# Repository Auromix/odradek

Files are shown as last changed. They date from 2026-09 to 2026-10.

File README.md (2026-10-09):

# Odradek

Current base candidate: [B06-COMPACT-07-DFM](engineering/base_b06/README.md), retaining the approved one-piece nose, wings and neck. Its build no longer requires arm assets; a separate metal test fixture and 21-test plan cover independent base qualification. [Shared base authority](docs/engineering/base-authority.md) applies to all arm-body work in Auromix/odradek; B04/B05 are historical references. Physical production qualification remains blocked.

**A 7-DOF desktop arm with a detachable four-petal luminous gripper, expressing attention through orientation, opening, and light.**

[中文说明](README.zh-CN.md) · [Design brief](docs/design-brief.md) · [Comparison](docs/concept-comparison.md) · [Nickname candidates](docs/nickname-candidates.md) · [Roadmap](docs/roadmap.md)

**Selected appearance directions:** the [dedicated selected-design folder](docs/concepts/selected/README.md) contains only the four-petal open silhouette and option B shield-shaped base. Other proposals and comparisons remain in the [research artwork directory](docs/concepts/README.md). Selection is not a manufacturing release.

**Current base work:** refine the single B06 source and integrate the arm against it. The approximately 239×224×71 mm exterior has five printed parts and underside fixings. The hidden clamp/inward box shelf have original CAD; IO and PWM lamp boards have native manufacturing exports. Prototype cables, actual connector release, fit and load qualification remain unfinished; this is not a complete base manufacturing release.

**2026-09-28 checkpoint:** preserve the current research and drafts without adding complexity. The preferred head uses positive single-input synchronization and permits one opposed petal pair to carry the grasp. Passive differential studies remain comparisons. [Saved scope and draft status](docs/engineering/checkpoint-2026-09-28.md).

Odradek is an independent Auromix robotics project sharing design material for noncommercial research and hobby use inspired by the articulated scanner in *Death Stranding*. The intended application is practical manipulation from a fixed desktop base. Mechanical design, appearance, and behavior develop together.

**Stage: engineering research; the head drive is being redesigned for a confirmed ≤1-second empty closed–open–closed cycle.** Gripping is the primary function and the illuminated petal face is the contact face. The user has confirmed a 2 kg net object plus head mass, approximately 700 mm reach, EtherCAT, GMSL/GMSL2 cameras, internal cabling and external computing. P16 actuators cannot meet the new cycle; their CAD and electrical branch remain historical references. The existing 7+4 assembly does not demonstrate the new speed requirement. See [current requirements](docs/engineering/fast-grasp-requirements01.md). No manufacturing release or tested 2 kg prototype exists.

## R5: single-drive head and separate arm body

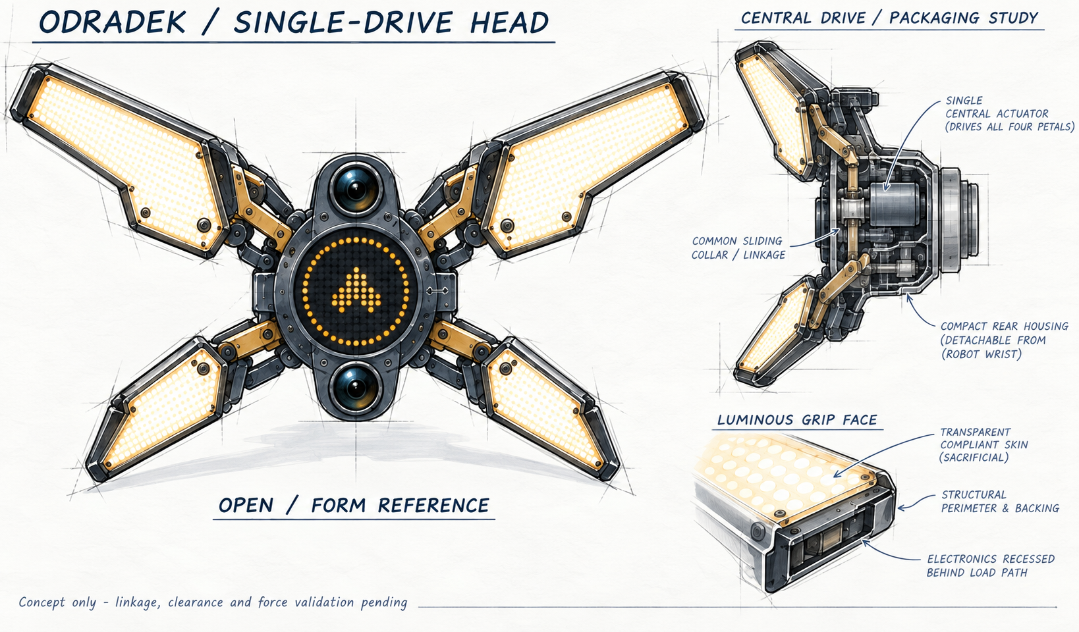
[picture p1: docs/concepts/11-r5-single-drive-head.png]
Single central drive and four shaped luminous petals


One concealed central actuator drives four coupled petals; their luminous faces also grip. The seven-axis body is developed separately with slender proportions and a detachable tool flange. [See both concept sheets and the current design brief](docs/r5-modular-design.md). Generated illustrations guide appearance; linkage, clearance and load capacity require engineering validation.

The latest engineering includes [revised layered petal STEP and drawings](docs/engineering/r5-petal-form02.md), a [fold-then-radial path and passive differential study](docs/engineering/r5-stage01.md), a [detachable eRob wrist adapter](docs/engineering/r5-wrist-erob01.md), and a [separate arm mass/reach study](docs/engineering/r5-body01.md). Everyday boxes, bottles and cans of approximately **50–120 mm gripping width** are the first target. Bare-petal geometry now has a continuous separation bound, but the physical mechanism, final closed posture and complete grasp range remain unqualified. The earlier [single-slider Blender rig](docs/engineering/r5-linkage-blender01.md) remains a separate comparison. See the [current baseline](docs/engineering/current-baseline.md) for evidence and remaining work.

The [native radial-candidate Blender model and guide](docs/engineering/r5-stage-blender01.md) contain 28 actual petal CAD meshes, including contact poses for an Ø80 mm cylinder and a 50×120 mm rectangular box. One mean input and three passive review offsets express the differential constraint; the physical transmission, central module and time simulation are not included.

## Engineering package

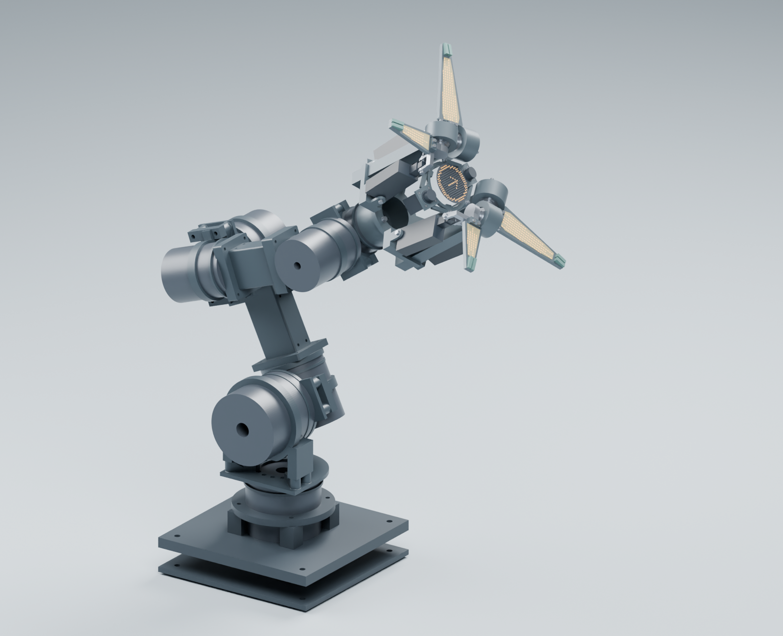
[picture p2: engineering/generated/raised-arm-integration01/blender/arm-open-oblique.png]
Existing structural review assembly — historical P16 head


This model combines 24 original link parts, a shoulder raised by 35 mm, the corrected base and the 697-object HEAD-INTEGRATED03 snapshot. Joint housings in Blender remain catalog envelopes; arm fasteners, harnesses and exterior guards are not fully integrated. The central pixel display is a separate visual preview. [The raised candidate](docs/engineering/raised-arm-integration01.md) passes the stated actual-BREP checks for ten poses, including the historical shoulder-collision pose. These discrete checks do not qualify trajectories or payload. [Current baseline and hardware choices](docs/engineering/current-baseline.md) separate the conditional eight-node P16 branch from earlier alternatives.

| Package | Evidence and scope |
|---|---|
| [Engineering index](docs/engineering/README.md) | Requirements, assumptions, source records, and release checklist |
| [R4 layout and grasp](docs/engineering/r4-layout-and-grasp.md) | Same-parameter geometry, closure proof, conditional contact calculations, and optical sightlines |
| [Existing native Blender / historical P16 head](engineering/generated/raised-arm-integration01/blender/odradek-integrated-7-plus-4.blend) / [model guide](docs/engineering/raised-arm-integration01.md) | 736 product meshes, 11 controls, persistent actuator linkage drivers; geometric review only |
| [Integrated head STEP and evidence](docs/engineering/head-integrated03-study.md) / [coupled dynamics](docs/engineering/articulated-dynamics-review.md) | Actual candidate solids, frozen board placement and explicit mass/inertia assumptions |
| [Historical layout](docs/engineering/r4-layout-and-grasp.md) / [subassembly scenes](docs/engineering/subassembly-blender-review.md) | Earlier design stages retained for traceability |
| [A3 review drawings](engineering/generated/layout/ODR-R4-assembly-review.pdf) | Axes, dimensions, and orthographic mesh views |
| [Manual finger fixture](engineering/generated/finger-fixture/README.md) / [joint interface coupons](docs/engineering/interface-coupon-guide.md) | Unpowered printable geometry checks with dimensions |
| [Hardware BOM](docs/engineering/hardware/bom.csv) / [optical bench](docs/engineering/hardware/optical-bench-build.md) | Sourced component candidates and a concrete dual-fisheye bench chain |
| [Reproduce the calculations and CAD](engineering/README.md) | Dependencies, generation order, units, and limitations |

The old [finite-pad contact counterexample](docs/engineering/finite-pad-contact-study.md) remains documented. HEAD-INTEGRATED03 now combines the revised CONTACT-02 pads and retention, narrowed CARRIER02 roots, lamp cavities, board placement and EXT24. Its 17 scoped continuous checks pass nominal geometry conditions; dynamic harnesses, tolerances, deformation and grasp testing remain unresolved. Conditional force calculations are not a measured payload rating.

## Historical R3: silhouette, closure and contact

The larger upper / smaller lower, left-right mirrored open silhouette is selected. The upper fisheye tilts upward and the lower downward; the amount remains open pending near-grasp visibility checks.

The study identifies three issues: unequal rigid lengths do not fold into one short common-depth pod, wide plates can collide before their tips reach the center, and forward curling turns the original luminous face toward the object. The leading candidate keeps each plate intact, uses different limits and real depth offsets, and places proud contact pads / structural borders on the light-facing side with recessed windows.

The [geometry study](docs/r3-closure-study.md) includes counterexamples and a continuous-domain separation result for an illustrative four-box model. This does not validate the full head or a stable grasp. The artwork's stow panel is an envelope study, not a final closed pose.

## Current direction: a detachable four-petal head

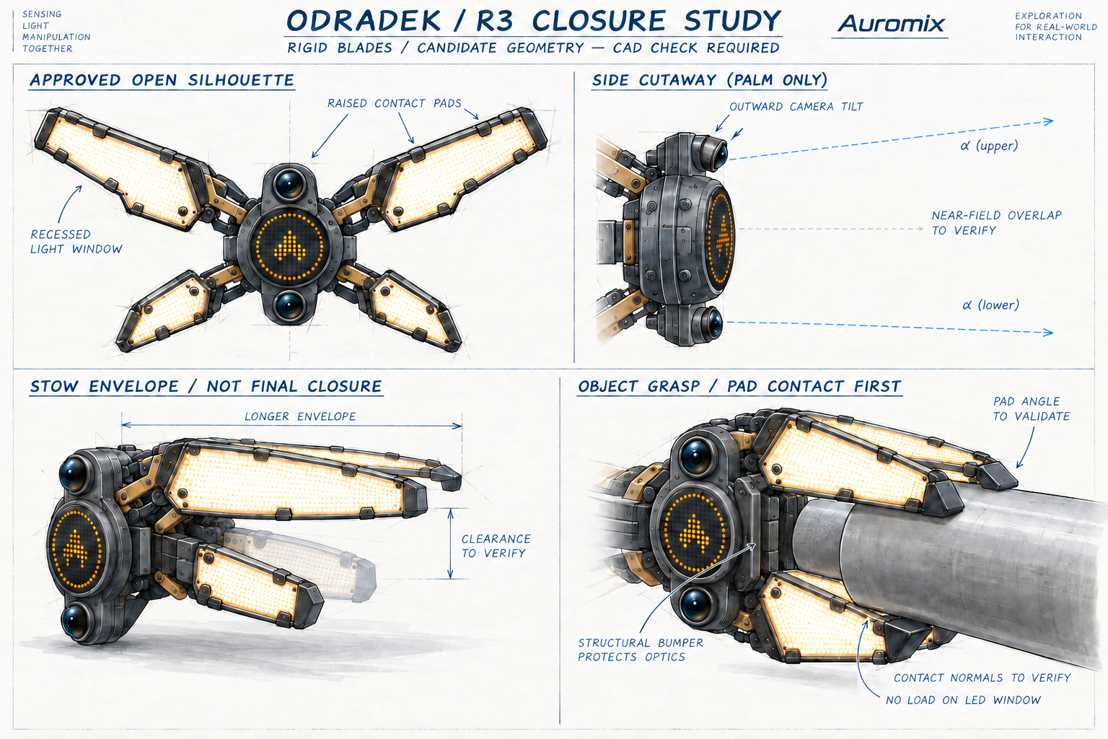
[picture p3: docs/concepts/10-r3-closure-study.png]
R3 silhouette, camera, and contact study


- **Seven arm DOFs; a single-drive four-petal head is now the preferred route.** J7 rolls the head about its front normal. One motor with three mechanically coupled followers is permitted; linkage mapping and passive compliance remain to be designed.
- **Two close petals on each side, with left/right mirror symmetry and different upper/lower proportions.** Longer upper and shorter lower petals avoid 180-degree rotational symmetry. The grouping is inspired by the XPENG logo composition; it does not require mechanically coupled pairs.
- **The light petals are the fingers.** Forward curling turns the light face inward. The latest requirement makes the illuminated face itself the gripping face; the contact skin and load-bearing support are being redesigned. Earlier proud tip pads are a historical contact study. Empty full closure must reach a mechanical limit with real clearances; it does not imply a sealed pod or four tips meeting at one point.
- **One circular LED display in the center.** Ring graphics use pixels at its perimeter. The four fingers provide lighting. Two fisheye cameras sit above and below the screen, tilt upward/downward respectively, and rotate with the head.
- **The detachable boundary is after the J7 output flange.** One concealed central actuator and local execution interfaces are proposed within the head; connection specifications remain open.

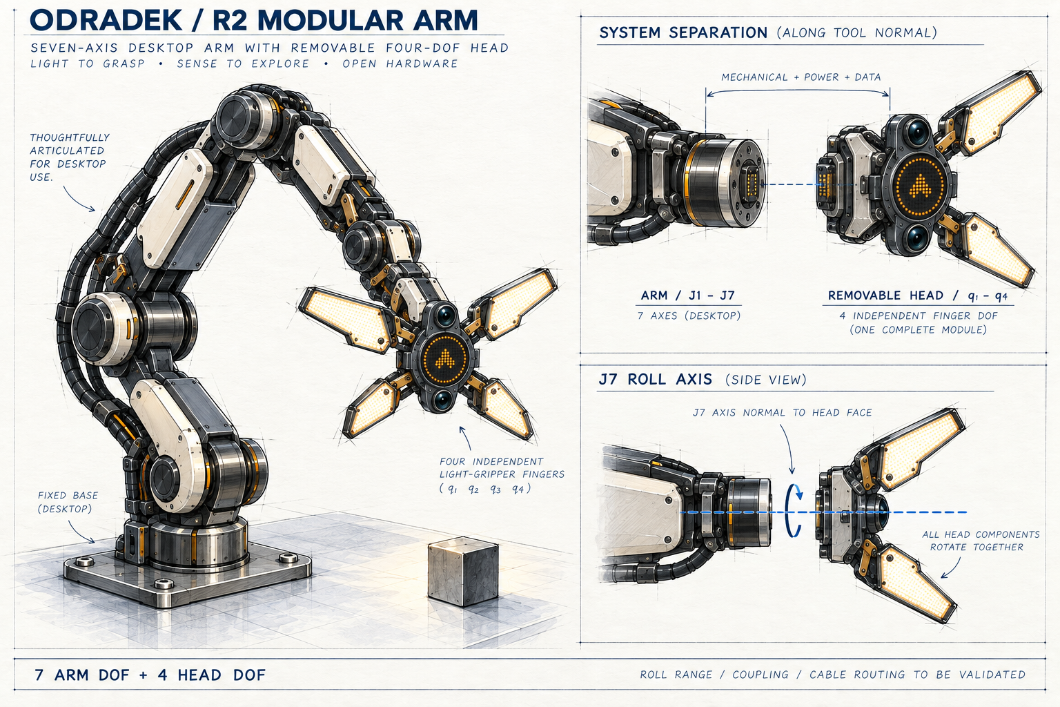
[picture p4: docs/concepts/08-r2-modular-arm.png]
Arm integration, detachable interface, and J7 axis


The roll sketches show finite-angle pose intent without defining travel. Open, grasping, and fully closed geometry must be reconciled in one CAD model; the R2 compact protective pod is now a historical assumption. Mechanical breathing is limited to empty, task-permitted operation; expression must not change an active grasp.

## Three, four, or five petals

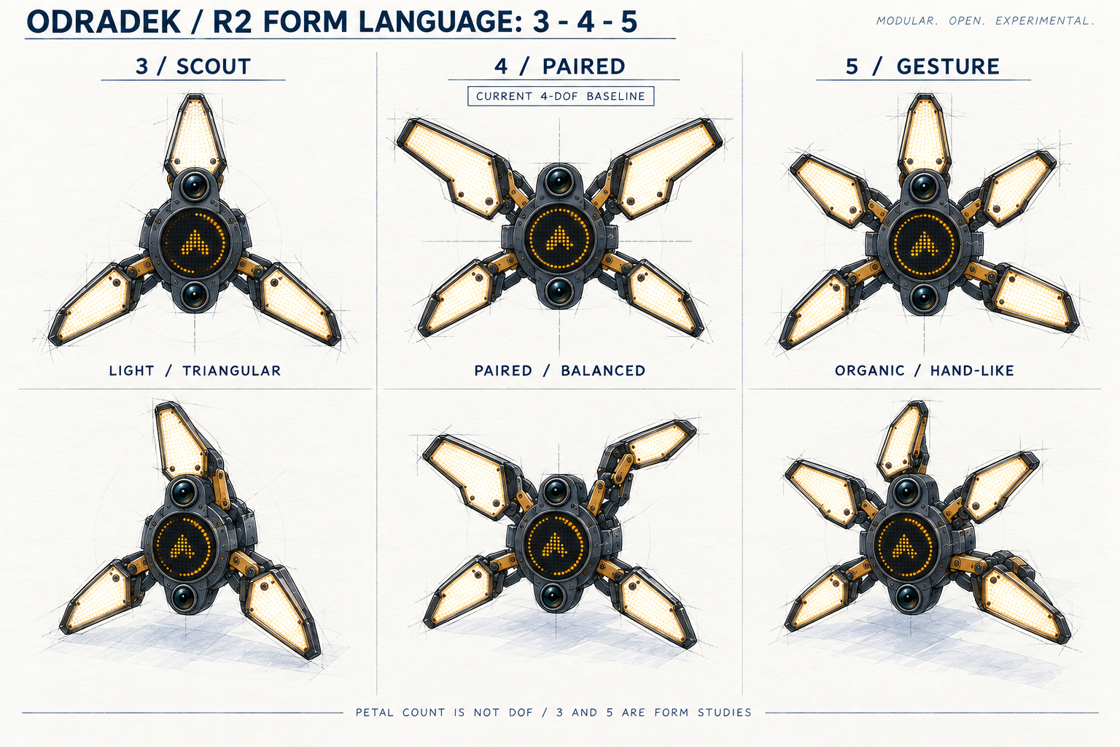
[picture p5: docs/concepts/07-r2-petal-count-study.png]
Same-scale petal-count study


| Count | Visual character | Role |
| --- | --- | --- |
| 3 | Light triangular silhouette; instrument or alien-tool associations | Aesthetic comparison |
| **4** | Two visually grouped pairs; balance between tool and creature | **Four shaped petals, single-drive coupling permitted** |
| 5 | Denser flower or biological silhouette; a hand-like reading needs an offset petal | Aesthetic comparison |

Petal count is not a DOF count. Three- and five-petal variants would require their own motion allocation; the latest direction permits a single actuator with coupled motion.

## Nickname candidates

**Odi** is the leading suggestion for continuity with Odradek; **Lumo** emphasizes light and breathing. Noto, Piko, Tavi, and Filo are additional options. See the [shortlist](docs/nickname-candidates.md). No nickname has been selected; the project and repository remain Odradek.

## Process and next steps

Research → R0 form exploration → R1 luminous fingers → R2 7+4 DOF and modular head → R3 silhouette and closure → **R4 sourced components, mathematics, CAD, and geometry fixtures** → complete load paths and harness routes → physical task and manufacturing validation.

The [gallery](docs/gallery.html) retains original R0/R1 artwork and exact prompts for traceability. R1's separate physical light annulus and finger-count candidates are superseded by R2.

| Document | Contents |
| --- | --- |
| [Design brief](docs/design-brief.md) | Confirmed requirements, concept assumptions, and open inputs |
| [Comparison](docs/concept-comparison.md) and [behavior](docs/behavior-spec.md) | Form, grasp, light, and attention studies |
| [Decisions](docs/decisions.md) and [roadmap](docs/roadmap.md) | Evolution and route to reproducible hardware |
| [Sources](docs/sources.md) | Research and reference roles |
| [Generation](docs/generation.md) and [review notes](docs/review-notes.md) | Prompts, AI assistance, and specific visual limitations |

Current open items include the shoulder's usable motion range, installed holding/thermal performance, complete controller and harness design, contact/fastener qualification and manufacturing tolerances. See the [release checklist](docs/engineering/release-checklist.md).

## License and commercial permissions

New original artwork, documentation, research scripts, parameters, and models are offered under **[CC BY-NC 4.0](LICENSE)**. Noncommercial research, study, hobby use, adaptation, and sharing are permitted under its terms. Sharing requires attribution, license information, and indication of changes. Commercial use requiring authorization needs a [separate written license from the authors](https://github.com/Auromix/odradek/issues/new?template=commercial-license.yml).

**Prior Apache-2.0 grants through `2d7d00f` and marked-script PolyForm grants in `698736a` through `c4f1fde` remain valid.** See [licensing scope and history](LICENSING.md), including the explicit limitations of applying CC to engineering research software. Future production control firmware needs a suitable separate license decision. Copyright notices do not themselves control all functional hardware manufacture.

The noncommercial restriction means this is not open source under the OSI definition. Contributions in English or Chinese are welcome; see [CONTRIBUTING](CONTRIBUTING.md). Third-party reference images are not included or relicensed. This project has no official affiliation with *Death Stranding*, KOJIMA PRODUCTIONS, or XPENG.

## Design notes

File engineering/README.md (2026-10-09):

# 可复现计算与建模

## 当前底座唯一入口

[B06-COMPACT-05-LIGHT](base_b06/README.md)是当前底座候选；沿用已确认的主罩外观；前鼻、双翼和颈台一体，五件打印结构，增加独立PWM灯板与隐藏M2固定，实际切片检查完成。所有本体模块遵循[底座同源规则](../docs/engineering/base-authority.md)，读取同一模型，不在本体目录维护可编辑的替代底座。B04/B05与下文R4底座只作历史研究。

新增原创工程研究源稿、参数及模型按 CC BY-NC 4.0 共享。历史 Apache / PolyForm 授权继续有效；CC 缺少软件专用条款的限制见 [LICENSING.md](../LICENSING.md)。依赖库保留各自许可，不打包重新许可。

`kinematics.py` 使用空间轴乘积形式计算位姿、Jacobian、重力、质量矩阵及数值 Christoffel 项；`gripper.py` 定义四片各自的径向转动与接触力映射。所有计算使用米、千克、秒和弧度；外部配置中的角度字段名称明确带 `_deg`。

代码不连接硬件、不发送运动指令。数值 IK 不包含碰撞或线束约束，质量和惯量假设必须在使用结果前核对。摩擦抓持下界不能作为力闭合证明。

## R5当前模块入口

[FORM02真实灯片](../docs/engineering/r5-petal-form02.md) → [STAGE01折叠/径向数学](../docs/engineering/r5-stage01.md) → [STAGE-BLENDER01原生模型](../docs/engineering/r5-stage-blender01.md)构成当前裸片研究链。Blender生成器为 `r5_stage_blender01.py`，先由CadQuery准备网格，再由Blender生成并以禁用自动脚本的进程重开核对。具体命令、输入及检查边界见模型说明。新的[eRob腕部接口](../docs/engineering/r5-wrist-erob01.md)单独保存，不与旧RH/P16整臂混成制造总装。

## 环境与单位

本版实际使用 Python 3.12.14、CadQuery 2.8.0 / OCP 7.9.3.1.1、Blender 4.5.14 LTS；其余 Python 版本见 [requirements-lock.txt](requirements-lock.txt)。记录的是本次环境快照，不保证所有平台均有对应二进制包。

```sh
python3.12 -m venv .venv
.venv/bin/python -m pip install -r engineering/requirements-lock.txt
```

以下命令从仓库根目录运行，`python` 应指向上述环境。Blender 使用自身 Python，不要往其中安装 CadQuery。需要中文图纸的命令通过 `--font` 传入可用的中文 TrueType 字体；字体不随项目分发。

参数源为 [r4-layout.json](parameters/r4-layout.json)。CAD 输入输出为 mm；数学核心为 m / kg / s / rad；Blender 网格转换为 m 后以 mm 显示。修改几何参数后必须按依赖重生成，不能只改渲染图。

## 数学与静力

```sh
python engineering/verify_math.py
python engineering/arm_screening.py
python engineering/head_mass_sensitivity.py
python engineering/review_arm_screening.py > docs/engineering/analysis/arm-static-independent-review.json
python engineering/grasp_screening.py
python engineering/finite_pad_contacts.py
python engineering/structure_screening.py
python engineering/structure_screening.py --check
```

数学回归覆盖解析单摆、耦合 2R、外力矩、Jacobian、势能梯度、动力学能量恒等式、可达/不可达 IK 和接触虚功。机械臂静力复核使用独立旋转递推与重量叉乘；梁模型有 60 项公式/数值检查。它们均不代表硬件验证。当前实机惯量、摩擦、转子耦合和热条件未知，不从这些检查推导额定速度或精度。

有限双垫研究读取已有主 CAD，计算物体先接触的实体、八点共享四轴力矩以及 BREP 反例。当前 Ø80 圆柱先碰骨架/灯窗，不能由旧单点例题推出可抓取；完整结果见[接触研究](../docs/engineering/finite-pad-contact-study.md)。

## 几何、图纸与 Blender

```sh
python engineering/build_layout.py
python engineering/certify_petal_separation.py
python engineering/check_layout.py
python engineering/check_optical_sightlines.py
python engineering/draw_layout.py --font /path/to/Chinese-font.ttf
blender --background --factory-startup --python engineering/build_blender.py
```

`build_layout.py` 读取当前参数、接口提取记录及已保存的指驱动布置输入；输出解析 STEP、单件 STEP/STL 和 manifest。STEP 可能包含导出时间戳，重新生成后的文件哈希不必字节一致；须重新生成引用这些文件哈希的证书并审阅几何变化。更换传动、支承或结构不能只复制旧分析结论。

分离证明只覆盖四片结构、灯窗和八垫的名义平面实体；采样碰撞另列对象和范围。碰撞布尔必须遍历每个 solid；直接对厂商 compound 求交会漏报，详见[安装接口研究](../docs/engineering/mount-interface-study.md)。

Blender 保存 7＋4 层级和 360 帧几何演示，另输出三视角渲染。原生层级 TCP 与独立矩阵计算在三姿态下检查到小于 0.001 mm。动画不含真实速度、加速度、控制或抓取轨迹资格验证。

新增 LINK56、固定底座及 CONTACT-02 的[原生分组件检查包](../docs/engineering/subassembly-blender-review.md)独立保存为 `generated/component-reviews/odradek-r4-subassemblies.blend`，含三个场景和五张渲染。使用 `export_component_reviews.py --output /tmp/odradek-component-meshes.json` 从已有 STEP 导出，然后由 Blender 执行 `blender_component_reviews.py -- --mesh-json /tmp/odradek-component-meshes.json`。它没有将三个研究机械集成为新整臂。

更新的[整体结构检查包](../docs/engineering/integrated-blender-review.md)保存为 `generated/integrated-arm-preview/odradek-integrated-7-plus-4.blend`，已合并六段24原创连接件、底座和HEAD03，736产品网格、11控制量。复现用 `export_integrated_arm_preview.py` → `blender_integrated_arm.py` → `review_integrated_blend.py`；具体命令与27条持久驱动、697件独立闭合CAD对照见说明。历史reach已查到肩部真实碰撞，不是可执行姿态；外壳、线束和完整臂侧紧固件尚未建成。

独立 [P16-PACK-01](../docs/engineering/gripper-linear-packaging-study.md) 把真实线性执行器接口、双剪销叉和近根支承接到 CONTACT02，尚缺整头载体。执行 `python engineering/p16_packaging_study.py --vendor-dir /path/to/vendor-reference` 后，再运行 `python engineering/p16_pin_stack_drawing.py` 和 `python engineering/p16_packaging_verify.py --vendor-dir /path/to/vendor-reference`。原厂CAD仅作为本地核对输入，公开包只包含原创保守包络；使用跳过检查的调试选项不能复用完整验证结论。

## 无动力打印件与接口研究

独立上灯片 [ULP-02原生KiCad](electronics/upper-petal-prototype/ulp02/kicad/README.md)含真实四层PCB、原理图、重放布线、逐针核对和C99例程。执行其 `rebuild.py --kicad-cli /path/to/kicad-cli --kicad-python /path/to/kicad-python` 可从源完整重建并实际运行ERC/DRC、317针网表和113灯点校验，再导出Gerber/钻孔审查文件。已在KiCad10.0.6独立重跑成功；这是电测样片，不是已经适配CONTACT02的正式灯板。

```sh
python engineering/build_interface_coupons.py --font /path/to/Chinese-font.ttf
python engineering/build_finger_fixture.py --font /path/to/Chinese-font.ttf
```

接口片使用已提取的真实孔坐标；单指台架包含打印方向、孔坐标、STEP/STL、五页尺寸图及几何限位检查。只能用于无动力形态/装配；与金属生产设计不同。厂商 STEP 不重新分发，需要重新提取或运行安装研究时，按对应[接口研究说明](../docs/engineering/mount-interface-study.md)传入自行取得的原厂文件。

## 文件成熟度

`generated/layout` 是 74 组几何布局，含明显占位及已记录的待修正问题；`generated/interface-coupons` 和 `generated/finger-fixture` 是无载打印检查件；`generated/mount-study` 是安装接口候选。**均不是完整制造发布包。** 参见[发布清单](../docs/engineering/release-checklist.md)，不要把能打开 STEP、网格水密或有限采样不碰撞等同于可承受 2 kg。

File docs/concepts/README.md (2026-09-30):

<!-- SPDX-License-Identifier: CC-BY-NC-4.0 -->
# 图稿目录

## 已选方向

[selected/](selected/README.md) 单独收录用户已选的四瓣末端展开外形与 B 收腰盾形底座。后续查看收敛图从这里进入。

## 研究与历史比较

[proposals/](proposals/README.md) 存放沿已选方向继续深化、待确认的新图，当前为 B03 内收盒架与靠墙布置；B02 外挂竖盒保留作历史。

本级带编号的图稿保留研究过程，不视为最终选项。R5 最新生成图也不自动表示用户已确认。

| 图稿 | 定位 |
|---|---|
| [11-r5-single-drive-head.png](11-r5-single-drive-head.png) | 当前末端深化提案，含未定传动布置 |
| [12-r5-arm-body.png](12-r5-arm-body.png) | 当前本体外观提案，未获整张图确认 |
| [13-base-study01.png](13-base-study01.png) | 历史 A/B/C 比较板；仅 B 外形被选定 |
| 00–10 各轮概念图、11-r3-geometry-check.png | 形态发散、历史状态或几何研究 |

[历史综合图集](../gallery.html) 保留完整过程；[决策记录](../decisions.md)说明每次选择的范围。工程输出继续放在原 engineering 目录，不因归档成为制造定稿。

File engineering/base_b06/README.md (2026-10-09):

<!-- SPDX-License-Identifier: CC-BY-NC-4.0 -->
# B06 当前底座：COMPACT-07-DFM 独立验证候选

开始打样前阅读 [首件打印与PCB准备](first-sample.md)，按当前五件STL和CONTROL01文件操作。

2026-10-09 CONTROL-01 增量：就地5V及STM32前灯控制候选已集成同一原生IO板和Blender模型，固件/主机协议数字测试通过。新增元件体与插合预算、既有五件打印切片进行同版复核。**当前IO PCB重建铺铜、保存复开后DRC为0**；本版26元件制造文件位于 `b06-io-control01`，历史13元件导出不可混用。详见[灯控候选与修复步骤](../electronics/base-io-b05/controller/README.md)。物理测试仍为0/21，未生产放行。

这是 Auromix/odradek 唯一当前底座源。外观、装配与接口板继续在同一仓库收敛，B04/B05保留为历史。**当前尚不是完整底座的制造放行包**；缺口见下方，不用几何检查替代载荷、真实插头或电气测试。

默认建模与验证不读取机械臂文件，机械臂仅为可选集成参考。[接口定义](interface-contract.json)固定法兰/供电/通讯边界；[独立验证方案](standalone-validation.md)、[21项验证计划](validation-plan.json)和[生产资格状态](build/qualification/qualification-status.json)覆盖不装臂时的完整底座检查。当前实物记录全部未测，生产状态BLOCKED。

2026-10-10 [底座—臂同源交接](arm-handoff.md)：底座优先，臂侧先适配；当前模型以 B06 文件指纹为准，过时上下文检查失败。该检查不代替实际拼接或载荷验收。

主罩维持约239×224×71 mm，前鼻、双翼与颈台一体；五件打印件适配256×256×256 mm打印空间，床边检查余量每侧5 mm。颈口Ø136，轴心XY(0,75)，Z0桌面，+Y朝桌内。主视觉面不新增固定孔。为承力底板增加后部下沿退出口，后盖保留四个独立接口窗。

## 当前文件

- [制造定义](manufacturing.md)、[分层制造BOM](build/B06-manufacturing-bom.csv)、[19步首件流转表](build/B06-first-article-traveler.csv)：纳入焊接、PCBA混合装配、端子叠层与未关闭线束，状态与实际证据分开记录。

- [Blender 总装](build/exterior/ODR-BASE-B06-COMPACT.blend)、[离线3D查看器](build/exterior/index.html)。本地预览通过HTTP打开。
- [独立试验工装3D](build/standalone-test/index.html)、[工装STEP总装](build/standalone-test/B06-standalone-fixture.step)、[工装加工评审图](build/standalone-test/drawings/B06-standalone-fixture-review.pdf)。这套工装不属于产品五件打印件，装置本身仍须校验后才能加载。
- [五件打印STL包](build/exterior/B06-print-fit.zip)、[打印件目录](build/exterior/print-parts/)。这个ZIP只包含打印件及当前几何报告，不含完整制造BOM。
- [机械BOM](build/B06-mechanical-bom.csv)与[装配顺序](assembly.md)：37行备料规划，含灯板及其隐藏紧固件，尚缺最终线束、光学垫片与外置盒电气项。
- [原生PWM灯板](../electronics/base-light-b06/README.md)、[灯板制造审计](../electronics/base-light-b06/reports/manufacturing-audit.json)、[灯板安装检查](build/exterior/light-fit-checks.json)。
- [实际切片评审](build/exterior/slice-review-checks.json)、[五件参考3MF](build/exterior/slice-review/)；参考P1S配置，实际打印机必须重新切片。
- [精确结构STEP总装](build/load-frame/B06-load-frame.step)、[分件STEP](build/load-frame/step/)、[结构清单](build/load-frame/manifest.json)。62个有效单实体（新增四条名义焊缝），包含环境和采购件包络；机械臂安装螺钉不再计入底座本体。螺纹用底孔加明确加工注释表示。
- [加工评审图PDF](build/load-frame/drawings/B06-load-frame-review.pdf)：从实际BREP生成的投影、包络、孔位表及加工注释，尚未作为全套制造图放行。
- [原生嘉立创接口板](../electronics/base-io-b05/README.md)：CONTROL-01原生板DRC0、26个实际元件，当前导出经独立审计；整板功能需首件验证。原生目录沿用B05命名，不代表采用旧底座。

## 当前结构与装配坐标

`load_frame.py`建立独立承力结构：S355上承力板、后沿腹板和双M12螺杆下夹板；6061法兰、四根金属间隔柱和向桌内延伸的可拆盒架。打印外罩/底架不传递机械臂载荷或桌夹预紧力。最大盒体预算180×150×50 mm、3 kg已获用户确认；从桌内方向(+Y)抽出，前限位条可拆。桌厚预算15–60 mm，后沿允许夹体和走线所需小间隙。

螺杆从下方用AF6内六角扳手转动。采购Ganter DIN6332-M12-100-SK与DIN6311-25-S；压脚Ø25平面朝上，经70×90×8金属分压板及2 mm保护垫接触桌底。模型只表达供应商尺寸包络，球面座、卡环与真实工具操作仍需样件核对。禁止将螺杆、压脚或承力件作为塑料STL打印替代。

法兰Ø160/ID56×12、上安装面Z58、PCD120八M6由独立接口定义固定，可连接测试适配盘或机械臂模块。四柱Ø18×29，顶底M8螺钉分别16/20 mm，名义有效咬合12.5/13.5 mm、两端尖端间隔3 mm。测试适配盘OD134可从颈口上方插入，八颗M6×20配1.6厚垫圈，名义咬合10.4 mm。机械臂OD140根座的下方装入顺序另列可选集成步骤。几何配合不等于承载证明。

接口板保持116×56×1.6 mm，额外相对冻结I/O快照位移(0,-10,+4)。板底Z24；四个安装点(X±52,Y−20/24)。原生EDA屏幕局部u/v(mm)转换为全局`(X,Y,Z)=(58-u,30-v,24)`。不缩放封装、焊盘和板框。PCB固定为M3×10，上垫面Z25.6，尖端Z15.6；内藏螺母Z19.2..21.6。金属底板对应Ø3.6孔避让螺钉末端。

双同轴另用B06-309金属支架，基座顶面保持原生H5/H6安装点(X±10,Y−8)，RF后向安装面Y−16，孔心Z35；不随RJ45/电源接口整体后移而顶穿后盖。

后盖两颗背向M3×10，轴高Z32；螺母在底架内，上装前放入。RJ45检修窗X27..49/Z23..44，48V窗X−52..−25/Z23..44，双同轴中心X±10/Z35、窗Ø14.8。板与元件仍为项目尺寸抽象，不能据此宣称原厂插头锁扣、插合基准和GMSL通道已经完整合格。

底架改由精确BREP生成后导入Blender，稀疏抬高支架避开钢板和PTH引脚；保留主罩四个隐藏M3固定点与两侧扎带耳。它不是承载底板。

## 当前验证与限制

- 五件STL：闭合、法向一致、单一面连通体、无退化/重复三角面，均通过256³包络检查。未修补失败STL；源几何重建后重新独立检查。
- 347组打印件之间、打印件与结构/I/O/灯板实体及GH插合预留交集：无超过0.01 mm³的穿透；该阈值只用于数值判断，不是加工公差。
- Blender复开：不含外部链接库或未打包图片依赖；本轮沿用独立工装的12条工具路径及底座分阶段装配工具检查；历史机械臂集成射线结果不列为本轮证据。机械臂参考未参与本次检查。
- 独立工装26个有效BREP分件；与金属底座无非预期交叠，与打印/电子件17组相交候选检查通过；12条M6/M8直线工具路径通过。工装尚无实物载荷资格。
- 13个后盖退出位置采样及四个原生EDA安装坐标通过；需要先拔插头、拆后盖螺钉。不是连续扫掠或靠墙原位拆卸证明。
- 15/30/60 mm桌厚的精确结构BREP静态检查通过。M12牙的底孔/大径包络重叠明确列为有意螺纹配合，不隐去其他干涉。
- 当前结构与采购件包络计算质量约7.5 kg，含桌夹/盒架/底架和标准紧固件，不含臂身、工装和控制盒；需减重与载荷计算后再冻结。简支梁筛查只是保守假设，不是额定载荷或有限元结论。
- 当前控制器板DRC0、Gerber/钻孔/原生网络复核通过；差分线长接近不等于整个通道已证明100Ω或EtherCAT合格。

## 完整底座打样放行仍须完成

1. 已补齐承力/盒架/同轴支架紧固件、加工孔位/螺纹/沉孔注释、装配次序和直线工具检查；仍需焊接工艺与实物工具/公差复核。
2. 已建立50×14独立PWM灯板，原生制造导出及引脚网络审计通过；当前隐藏M2安装和GH插合空间进行同版装配检查。灯窗软垫、透光样件、板上48V→5V/PWM控制电路和内部短线仍需关闭；严禁直接接48V。LED板原生STEP部分有效BREP在三角化时接缝不闭合，这些子实体明确以其原生BREP包围盒作保守干涉检查，不把替代包络当作原厂精确模型。
3. 真实电源插头/RJ45锁扣/双同轴接头与线材的插合、释放、弯曲和应变释放；现有保守包络不是采购闭环。
4. 切片及小样配合公差检查、完整制造BOM、当前PDF尺寸/孔表与STEP/STL/PCB指纹一致性。
5. 完整无动力打样装配文件放行；样件回来后按独立流程做桌夹防滑/桌面压力、通电温升/保护和链路测试。制造文件放行与带载运行放行分开。

## 复现

用含CadQuery、trimesh、manifold3d、numpy、scipy、shapely、reportlab及svglib的Python运行`verify_base.py --blender /绝对路径/Blender`；添加`--render`生成评审图片。重建默认拒绝读取臂身文件并记录输入哈希。现有切片需与实际STL的顶点及三角面匹配，不匹配即停止。机械臂参考通过`blender_compact.py -- --with-arm-root --no-render`输出到单独`build/arm-integration/`；它不是第二份底座源。修改后重新生成受影响报告及指纹，实物记录版本失配后不可沿用。

CC-BY-NC-4.0；Odradek / Auromix contributors。

2026-10-09供电修订：前灯目标由底座板就地产生5V，经内部短GH线连接；原生IO板现已加入就地5V供电，当前导出在b06-io-control01；STM32 PWM与UART命令已在原生板及固件中实现，实板仍未验证。新增元件按独立底座装配包络验证，实物供电、浪涌、温升及EMI待测。

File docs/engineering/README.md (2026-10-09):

# 工程开发记录｜R4历史与R5单驱动深化

## 当前底座唯一入口

[B06-COMPACT-07-DFM](../../engineering/base_b06/README.md)为当前同源候选，保留已确认外观；[底座同源规则](base-authority.md)定义本体引用、只读快照和更新后的联检。B04/B05及下表R4固定底座属于历史，不与B06并列维护。

本轮从概念研究进入参数化工程设计。用户要求持续推进硬件选型、机械臂与夹爪数学、Blender 结构模型及制造图，并按完成部分提交。本目录将输入、计算、供应商证据、设计产物和验证记录分别维护。

先看[FAST-GRASP01最新需求](fast-grasp-requirements01.md)和[当前基线](current-baseline.md)：灯片面必须用于正常夹持，空载完整开合≤1秒。P16退出主末端路线；既有模型与电路保留为可复现研究。七轴本体、中央屏、灯板及相机继续作为新方案输入，不能把历史研究混成已满足新要求的采购配置。

[R5单驱动末端与独立本体](../r5-modular-design.md)包含最新概念图及确认输入。[SHOULDER-RAISE03](shoulder-raise03.md)已合并让位钢块与具体螺钉；[HEAD04](head-integrated04.md)和[HEAD-POWER01](hardware/head-power01.md)归档为旧P16集成证据。

R5最新工程入口：[削肩灯片FORM02与二维图](r5-petal-form02.md)、[折叠后径向夹持/差动数学](r5-stage01.md)、[eRob可拆腕接口](r5-wrist-erob01.md)、[独立本体质量/臂展](r5-body01.md)、[轻量EtherCAT关节](hardware/r5-light-joint01.md)、[透明夹持面材料与紧固件](hardware/r5-petal-hardware01.md)。盒体、瓶罐50–120mm为确认目标，现阶段没有完整抓取范围资格。较早[单滑块数学](r5-link01.md)、[一个主控的原生Blender](r5-linkage-blender01.md)和[折返带传动](hardware/r5-folded-drive01.md)保留为固定根轴比较方案，不与新径向机构混算。

## 当前可查看的工程结果

| 部分 | 入口 | 已有证据及边界 |
|---|---|---|
| 两瓣主夹持新口径 | [TWOCONTACT01](r5-twocontact01.md) | 同步四瓣先夹盒体较大尺寸；每片约49N初筛与804N根轴承反力，有限接触斑抗转仍是条件模型 |
| 当前径向候选 Blender | [STAGE-BLENDER01](r5-stage-blender01.md) | 28个真实灯片CAD网格，展示圆柱与长方盒的不同半径接触；一个主动输入加被动评审偏移，未模拟真实差动传动 |
| 径向折叠随动器与根轴承 | [CAM-HARDWARE01](hardware/r5-cam-hardware01.md) | CFS4、双607/8-2Z、真实安装栈与逐片受力；保留大悬伸、远端接触及低摩擦下的不足 |
| 径向载体与分体根轴 | [CARRIER01](r5-carrier01.md) | 40种单件、实际短轴/曲柄/轴承/导槽及2页名义尺寸图；内件C4、无硬止挡/掌体/滑轨，256.53mm外包尚未外观协同 |
| 差动钢索、滑轮与终端 | [CABLE-HARDWARE01](hardware/r5-cable-hardware01.md) | 一套升级索轮候选、名义50/100N条件筛选；全公差、端部保持力和完整索路尚未验证 |
| 七轮差动索路包装 | [ROUTE01](r5-route01.md) | 恒索长中心线、真实轮径、偏置支承载荷与独立复算；仅轮组已到根铰后239.05mm，不作为紧凑头定案 |
| 单电机被动开合动力学 | [PASSIVE01](r5-passive01.md) | 上下瓣不同步与首次止挡的独立数学核对；先碰止挡后不能继续套用绷紧钢索约束，完整周期仍未验证 |
| 实际载体质量与回位搜索 | [PASSIVE02](r5-passive02.md) | 加入0.689221kg已建移动件、238组有限参数；不能实现完整同步周期，强阻尼和静态夹力的代价已量化 |
| eRob两轴腕部连接 | [WRIST-PAIR01](r5-wrist-pair01.md) | 一体连接件和薄裙接口、5页图与无载样件；真实固定侧螺钉纳入，线束/完整牙/强度仍待闭合 |
| eRob J5至J6细长连接 | [LINK56-EROB01](r5-link56-erob01.md) | 282g原创闭口梁、孔/工具/装入/局部运动与静载证据；底部转线具体反例保留，完整内束和整体强度未放行 |
| 单驱动运动与夹持需求 | [FAST-KIN01](fast-finger-kin01.md) | 真实单位的虚功、非线性映射项、1秒空载轨迹、接触顺应反例及转子回生；机构仍待综合 |
| 中央执行器候选 | [FAST-DRIVE01](hardware/fast-drive01.md) | 单3274+32GPT HT50与AK70/直接丝杆比较；空载速度筛查通过，静止热及实际夹力未获得资格 |
| 结构布局 | [R4 布局、闭合与抓取](r4-layout-and-grasp.md) | 同参数 74 组 STEP、7＋4 Blender、A3评审图；连接与动态线束未完整 |
| 本体数学 | [运动学与动力学](arm-mathematics.md)／[静力独立审查](arm-screening-review.md) | 解析回归、独立重量叉乘、质心敏感性；非实机额定值 |
| 独立动力学复核 | [DYNAMICS-REVIEW01](rigid-body-dynamics-review.md) | 五段21实体CAD惯量；24组独立力/矩法、拉格朗日与能量检查一致，剩余质量代理/转子/热仍未验证 |
| 7＋4耦合动力学 | [DYNAMICS-11DOF01](articulated-dynamics-review.md) | 六段24实体＋整头13刚体，去除重复L7预算；解析Jacobian/直接刚体力矩/能量/推杆虚功一致，未计量余量与夹持接触负载仍需加入 |
| 夹爪数学 | [当前抓取 LP 审查](grasp-screening-review.md)／[独立角域分离](petal-certificate-review.md) | 72 个条件接触场景；16 实体独立角域闭合证明，不含完整支承 |
| 实际物体接触 | [有限双垫研究](finite-pad-contact-study.md) | 八点共享四个指轴；Ø80 圆柱先碰骨架/灯窗，接触结构待修正 |
| 双垫受力分担 | [最低共同力矩上限](paired-pad-loadsharing.md) | 90种分担/摩擦/直径；区分一组最小夹力解与最低所需驱动上限 |
| 片尖接触鞋 | [CONTACT-02](distal-contact-study.md) | 150/100 mm 长短片、64 项实体复核；改善指定圆柱接触，驱动力矩仍需匹配 |
| 接触材料试片 | [双型四腔浇注模具](contact-pad-prototype.md) | STEP/STL/DXF/两页图纸；未打印/浇注，不含保持结构或承载资格 |
| 软垫保持候选 | [贯穿浇注键](contact-pad-retention-study.md) | 8个实体与两页特征图，保持名义外轮廓；偏心剥离和材料抗撕裂仍待验证 |
| J5→J6实体连接 | [LINK56-01](link56-structure-study.md) | 六件原创结构、40紧固件、六页图与分步装配；有效螺纹/预紧/局部强度未放行 |
| J1→J2肩架 | [LINK12-01](link12-structure-study.md) | 三件原创结构、五页图及J2连续插入证明；0.745 kg含紧固预算，预紧/材料/行程未放行 |
| J2→J3实体连接 | [LINK23-01](link23-structure-study.md) | 三件原创结构、28螺钉、五页图与四步连续装入证明；完整牙/预紧/全行程未放行 |
| J3→J4实体连接 | [LINK34-01](link34-structure-study.md) | 六件原创结构、40螺钉、六页图；q3相对J2/L23全周和连续装配已检查；后环接触刚度/预紧/完整牙待验证 |
| J4→J5实体连接 | [LINK45-01](link45-structure-study.md) | 三件原创结构、28个已知螺钉形状、六页图；局部q4/q5连续避让和装入已检查；动态相机线首弯存在明确碰撞 |
| 新增部件 Blender | [三个原生场景](subassembly-blender-review.md) | 连接件、底座和四指；五张渲染、12项层级变换检查，尚非新整机装配 |
| 当前肩部抬升总装 | [RAISED-ARM-INTEGRATION01](raised-arm-integration01.md) | +35mm肩架、736网格/11控制、10个真实实体姿态无交叠、派生数学模型独立通过；全臂路径/线束/结构强度未放行 |
| 原版结构 Blender 总装 | [原736对象与11个控制](integrated-blender-review.md) | 历史原版保留，reach存在肩部碰撞；由抬升候选继续推进 |
| 六段承力连接 | [真实接口与空间审查](link-connection-plan.md) | 全部接触面/孔阵；发现肩部螺钉及两段旧梁干涉 |
| 真实连接质量回算 | [LOADS-02肩架集成](shoulder-mass-integration.md)／[LOADS-01](candidate-loads.md) | LINK12+LINK56九实体惯量/COM回填；重头情景与底座重算，仍非整机载荷上限 |
| 末端质量影响 | [3.5–4.5 kg 敏感性](head-mass-sensitivity.md) | 2 kg净物体另计；局部搜索及全域保守界，不替代动态/热选型 |
| 材料与梁 | [截面筛选](structure-screening.md) | 6061-T6 闭口矩形梁与双管比较；不含完整连接柔度 |
| 底座 | [开腔底座及倾覆计算](base-structure-study.md) | 5种原创零件、8件装配、4页图；固定到桌架的候选，未承载放行 |
| 历史直线指驱动 | [LINEAR-01](linear-finger-drive-study.md) | 独立曲柄正逆解／速度／夹力；单程约18秒，已因1秒空载往返要求退出主路线 |
| 四路推杆控制候选 | [P16-CTRL01](p16-control-interface.md) | 4×DRV8874、12V/6A外置电源、反馈反解和静态限流角落；8从站为条件分支，实际PCB/力与占空未验证 |
| 真实直线驱动封装 | [P16-PACK-01](gripper-linear-packaging-study.md) | 原厂配合、双叉肩轴与四组独立运动；建模1.423 kg，后伸14 mm，载体/J7路径待补 |
| 窄根可拆接口 | [SUPPORT-03](gripper-root-support-study.md) | 真实键轴、叉、螺钉与捕获螺母；完整名义角域避让通过，公差/强度未放行 |
| 指轴支承 | [单指双支承与四组反例](gripper-shaft-support-study.md) | 修正带轮真实宽度，否定旧紧凑切向布局；正在重新布置传动 |
| 接口 | [试装片](interface-coupon-guide.md)／[J1与J7安装](mount-interface-study.md) | 原厂真实孔位、逐实体避让、原创尺寸图；螺纹有效起点等未冻结 |
| 打印台架 | [单指手动台架](../../engineering/generated/finger-fixture/README.md) | 四件打印件与五页图纸，无动力无载 |
| 元件 | [主 BOM](hardware/bom.csv)／[BOM口径](hardware/bom-notes.md) | 候选、blocked 和 TBD 逐项区分，不是一键采购整机表 |
| 关节运行与接口证据 | [RH-OPERATION-EVIDENCE01](rh-operation-evidence.md) | 四精确型号、官方ESI与固件关系；确认B闸无需独立外供24V、J7 N无闸；零速热额定/停止时序/满牙区间仍缺 |
| 历史P16控制电路 | [HEAD-CTRL02](hardware/head-ctrl02.md) | 100脚MCU/ESC、四路H桥、242器件原生电路；ERC0、833连接脚一致；8站条件分支，无PCB/通电资格 |
| 控制器具体被动件 | [HEAD-PASSIVES01](hardware/head-passives01.md) | 193个待定位置补齐MPN、23种板上料号及维修帽；11处封装变更、128温漂端点，未修改冻结电路或放行PCB |
| 当前内走线 | [HARNESS02](hardware/internal-harness02.md) | 真实孔与装壳FAKRA、J5缓S弯；夹持策略和动态长度仍待闭合 |
| 历史BLDC电气 | [架构](electrical-architecture.svg)／[旧线束](harness-and-connectors.md) | 7本体＋4指伺服＋1头IO，共12站，仅属BLDC替代分支 |
| 动态相机线补查 | [CAM-CABLE02](camera-cable-refresh.md) | CG03现行PDF、R34.5/R37候选及资料冲突；半径较小的候选未获动态/通道资格 |
| 工件可见性 | [实际圆柱遮挡](grasp-object-visibility.md) | 两相机可见端面45采样点；八接触点被工件遮住，需独立接触反馈 |
| 光学台架 | [采购和搭建](hardware/optical-bench-build.md) | 双鱼眼、Duo采集、AGX Orin及固定驱动链，尚未实装 |
| 单轴台架 | [采购和搭建](hardware/single-axis-bench-build.md) | IPC、电源、原厂通信转接及未放行针脚/保护项 |
| 上灯片电子样片 | [ULP-02 原生四层PCB](hardware/upper-petal-ulp02.md)／[ULP-01历史电路](hardware/upper-petal-prototype.md) | 113 LED、134器件、317针、39网；实跑ERC/DRC/未连/网表一致性均0，已导出制造审查文件，未实测或装机放行 |
| 灯片真实层叠 | [电子腔与PCB安装](led-petal-pocket-study.md) | 4.45 mm普通层叠、安装柱/低头螺钉和净截面计算；GH/线束与正式灯板未集成 |
| 正式灯板适配 | [上下片130/42点阵候选](final-petal-board-fit-analysis.md) | 212项实体包络容纳检查；侧插GH、焊高/局部深腔与热桥待ECAD/MCAD联合收敛 |
| 上下片原生电路 | [FPL-01](hardware/final-petal-fpl01.md) | 130/42点、六层0.8mm候选；完整重建ERC/DRC/未连/网表一致性均0，位置与HEAD03一致；层叠/填孔/去耦/温升未制造放行 |
| 腕部承力连接 | [J6—J7三件结构](link67-structure-study.md) | 24螺钉、零位/工具/J7连续装入已检查；末端旋转碰撞和生产公差未闭合 |
| 头部腕区避让 | [24mm加高与连续证明](wrist-extension-study.md) | q5/q7±90、q6±90及四指独立范围，头对相关腕区名义下界2.9mm；未含全臂/线束/受载公差 |
| 整臂真实实体筛查 | [六态与LINK67连续转动](integrated-collision-study.md) | zero/inspect两种指态无新增交叠；历史reach肩部有3对真实碰撞，不可执行；LINK67自身对J6/L56覆盖q6±100，尚非完整联合运动域 |
| 现状肩部几何边界 | [SHOULDER-DOMAIN01](shoulder-domain-01.md) | q2±25局部连续下界1.245mm、±20为2.643mm；首次阻塞约±27.42°，不改实机控制限位 |
| 肩部抬升候选 | [SHOULDER-RAISE01](shoulder-raise-study.md) | J2及下游抬高35mm、加长真实后叉；局部q2±90连续域最小4mm，增重0.127kg；整臂联动/结构刚度未放行 |
| 加高肩架受力初筛 | [SHOULDER-RAISE-STRENGTH01](shoulder-raise-strength-study.md) | 真实77.8mm跨度、13状态反力、孔组/净截面/梁族参照；识别薄曲环与铝牙边缘问题，未做FEA或承载放行 |
| 加强肩架候选 | [SHOULDER-RAISE02](shoulder-raise02-study.md) | 厚后环、双后柱、8块钢螺纹块；名义装入与局部运动通过，金属增重0.563117kg；真实接触/预紧未放行 |
| 肩架采购条件 | [SHOULDER-PROC01](hardware/shoulder-procurement01.md) | 6061-T651厚板、完整坯料包含检查、M4×100具体候选；受控公差/有效螺纹/材质批次仍待确认 |
| 肩部尾盖接口避让 | [SHOULDER-PORT01](shoulder-port01.md) | 两块钢件34→38mm独立候选、36连续开口通道与84原厂实体检查；未把开口通行当真实插头插拔资格 |
| 完整末端载体 | [P16-CARRIER-01](p16-carrier-study.md) | 四轴承座/P16基叉/J7后架/双鱼眼前架及236实体端态；2.727kg已建模型，根部小间隙与腕旋转仍需修订 |
| 灯爪近根修订 | [P16-CARRIER-02](p16-carrier02-study.md) | 四路同轴支承全角域名义间隙1mm；增厚钢桥、孔后截面和反力已计算，2.747kg已建模型；延伸件/正式灯板待合并 |
| 四瓣整头集成 | [HEAD-INTEGRATED03](head-integrated03-study.md) | CARRIER02＋灯腔/软垫保持＋FPL机械快照＋EXT24；两态各697实体、17项连续检查，计量模型2.802kg、规划2.987～3.252kg；电气路由/线束/护壳未定版 |
| 整头质量与惯量 | [HEAD-MASS04](head-mass04-study.md) | 262项聚合为13个刚体、重2.802kg；精确实体积分与目录惯量代理分列，P16质量分配/未知185～450g预算明确，不重复旧L7占位 |
| 历史灯光与IO | [HLIO01的609点研究](hardware/head-lighting-io-selection.md) | 历史285+2×113+2×49；当前FPL01四片344、中央拟285，合计629点，电源预算不能混用 |
| 末端控制板空间 | [HEAD-CTRL-VOLUME01](head-control-volume01.md) | 56×64×30mm完整电子装配预留，固定件最小2mm、四指/P16连续分离；实际PCB/插头/支架/热路径尚未集成 |
| 中央圆屏安装 | [CD-MOUNT01](central-display-mount01.md)／[独立装拆审查](central-display-review01.md) | 285点、Ø60PCB、杯座/压框/窗口/侧耳、GH12参考；连续避让和全开装拆空间通过，材料/公差/实际中央板与线束待闭合 |
| 中央屏几何样件图 | [CD-DRAW01](central-display-prototype01.md) | 4页A3、9份mm DXF、4个无电打印样件，保留杯座前后不同截面；不是金属制造公差版 |
| 中央屏原生电路 | [CD-EC01](hardware/central-display-cd01.md) | 285点/318器件、双LP5860、GH12逐针与ERC通过；PCB、热与整头装配另行审查 |
| 中央屏六层PCB | [CD-PCB01](hardware/central-display-pcb01.md) | 318器件、285点实际布线；独立原生DRC/未连/原理图一致性均为0，背面33器件MCAD分实体最大盒与规划包络；19个焊盘关联通孔须填孔盖铜审查 |
| 复现 | [运行说明](../../engineering/README.md) | 固定依赖、生成顺序、单位与输出边界 |
| 肩部实体刚度比较 | [SHOULDER-FEA01](shoulder-fea01.md) | 8网格24解、线弹性二次四面体、主收敛与同支承敏感性分开；尚不是螺栓接触/疲劳/整臂负载资格 |
| 放行差距 | [发布检查清单](release-checklist.md) | 对应证据和实际未完成事项 |

## 已确认输入

| 项目 | 约束 |
| --- | --- |
| 使用形态 | 桌面或固定底座，执行实际操作任务 |
| 外形 | 细长、科幻机甲感；石墨色承力结构、克制的金属／琥珀色细节，与已选四瓣头部搭配 |
| 自由度 | 本体7轴，J7轴线垂直末端正面；最新末端允许1电机＋3瓣mimic，不要求4独立驱动 |
| 末端 | 上两瓣大、下两瓣小、左右镜像；灯片兼作夹指；中央圆 LED 屏；上下两鱼眼分别上下外倾 |
| 载荷要求 | 用户已确认2kg工件净重，另计可拆末端模块自重 |
| 臂展目标 | 用户已确认约700mm，按肩关节到工具中心理解；当前零姿态746mm布局仍需工作空间审查 |
| 相机接口 | 用户已确认GMSL／GMSL2同轴接口；具体完整链路仍需兼容和动态线束验证 |
| 通信 | EtherCAT；图像接口另行选型，不把相机视频封入运动总线 |
| 布线 | 内走线；各轴有限转角，与线束扭转和弯曲寿命共同确定 |
| 计算 | 控制器与视觉计算可外置；本体主要承担执行、驱动及接口导出 |
| 制造路线 | 首先 3D 打印验证形态／装配，再使用金属制造承力结构 |
| 工作方式 | 持续推进、分部分 commit；已有 GitHub 同步授权继续有效 |

## 工作假设与已确认状态

2026-09-27的[用户确认记录](confirmed-inputs-2026-09-27.md)取代旧文稿中A01、A02、A04的待确认状态。旧参数文件保留其计算快照，不会因确认动作自动改变几何或额定值。

| 编号 | 假设 | 对结果的影响 |
| --- | --- | --- |
| A01 → 已确认 | 2kg净工件，另计可拆末端模块 | 与当前研究计算口径一致 |
| A02 → 已确认近似目标 | 肩关节到TCP约700mm；当前抬升布局零姿态约746mm，旧R4-layout-03约722.10mm | 不是全姿态最大值或可达球半径；有效工作空间由关节和碰撞约束决定 |
| A03 | 旧主参数仍保留2 kg头部假设。P16条件分支HEAD-INTEGRATED03可计量模型2.802 kg、规划2.987～3.252 kg；历史直角驱动分支规划3.577～4.252 kg，另有3.5～4.5 kg预算头载荷研究 | P16已因1秒空载往返要求退出主路线，新伺服头须重新称量/计算；所有质量均非实重，计算须声明具体分支与COM |
| A04 → 已确认类别 | 相机使用GMSL／GMSL2同轴接口 | 具体相机、视频采集板、线缆和连接器必须形成经验证的兼容链 |
| A05 | 初期为低速桌面任务，运动周期、加速度和精度尚未给定 | 初步静载筛选不能证明连续热性能、动态寿命或精度 |

## 交付与提交顺序

1. 工程输入、许可边界、可追溯参数和验证计划。
2. 供应商一手资料、关节／电气／光学／手指候选与选型差距。
3. 同源机械臂与夹爪参数、运动学、力矩、接触和结构计算及独立数值检查。
4. 精确实体 CAD、可打印分件与同参数 Blender 装配／动作模型。
5. 对应真实零件的尺寸图、BOM、装配和线束文件；依供应商图纸／分析证据逐件提升成熟度。
6. 交叉检查几何、图纸、数学和选型；发布可复现工程包与未关闭事项。

## 成熟度标识

- **设计输入**：用户已确认，或明确编号的工作假设。
- **候选**：有可追溯型号与数据，但兼容性、尺寸或负载条件还未全部满足。
- **计算通过**：仅在注明模型和载荷范围内通过；不能扩展为样机测试通过。
- **可打印形态件**：几何闭合并适合形态装配验证，不代表可带 2 kg 负载运行。
- **制造评审图**：包含尺寸与工艺意图，但还存在明确的冻结项。
- **制造发布图**：关键接口、材料、尺寸、公差、载荷及装配闭环已核验，并完成对应制造审核；不得由渲染图或包络模型自动取得该标识。

当前没有制造发布图，也没有 2 kg 样机试验结论。研发过程将持续记录并解决差距，不把未知孔位、线缆寿命、驱动安全功能或摩擦系数填成确认事实。

## 精确几何与 Blender 分工

参数文件是结构、运动学、BOM 和出图的共同输入。CadQuery／OpenCascade 的边界实体用于 STEP、STL、截面与尺寸依据；Blender 用于装配层级、关节运动、造型与内走线展示。Blender 的网格渲染不代替精密配合与公差定义。

历史外形依据见 [R3 设计简报](../design-brief.md)及[夹片闭合研究](../r3-closure-study.md)。

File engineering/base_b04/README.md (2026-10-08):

<!-- SPDX-License-Identifier: CC-BY-NC-4.0 -->
# B04-P2 底座历史三维审查包

**当前底座已切换为[B06-COMPACT-02](../base_b06/README.md)。** 本包仅作历史结构研究；其桌夹、底板、接口与检查结果不能直接移用于紧凑B06。见[同源规则](../../docs/engineering/base-authority.md)。

本包只深化桌面机械宠物的底座：飞碟盾形外罩、隐藏桌夹、内收盒架和后部接口。它是供外观、装配及打样评审的工程候选，尚未制造放行。

- [可旋转三维模型](build/index.html)：自包含 WebGL，可开关模块、展开、切换桌厚；“如何拧紧”显示长内六角工具。
- [Blender](build/ODR-BASE-B04-P2.blend)：按模块分组的实际 CAD 网格，可继续编辑；不是参数化加工源。
- [STEP 总装](build/ODR-BASE-B04-P2.step)、[GLB](build/ODR-BASE-B04-P2.glb)、[零件/孔特征清单](build/manifest.json)、[零件 BOM](build/parts-bom.csv)。加工几何以 STEP、特征清单及源参数共同为准。
- [前罩近景](build/shield-closeup.png)、[全装配](build/assembled.png)、[内部](build/open.png)、[后侧](build/rear.png)。图像由同一 CAD 导入 Blender 渲染。

## 这一版的形状和模块

外罩是围绕中央环座展开的低矮曲面护盾，保留宽肩、收腰、下扣的外沿。曲面由相互对应的周期样条截面分段放样；前后两罩以 0.8 mm 分缝分开。中央承力法兰独立，外罩不承担机械臂载荷。前方琥珀灯窗随肩部曲面变化，背后是独立 50×12 mm 灯板。

三块 PCB 各自独立：

| 模块 | 工作内容 | 本轮交付 |
|---|---|---|
| [服务板](../electronics/base-b04/README.md) | 本地低压服务、电源状态和灯驱动等，边界以其电路文档为准 | 原理图、PCB、BOM、制造导出、机械包 |
| [前灯板](../electronics/base-light-b04/README.md) | POWER / RUN / FAULT 三路 LED，四芯线接服务板 J3 | 原理图、PCB、STEP、安装/线序合同 |
| [后接口板](../electronics/base-rear-interface01/README.md) | 板载 EtherCAT RJ45 转接、48 V 接口和接地；同轴另走机械支架 | 原理图、PCB、连接器/插头范围、STEP |

后接口朝下，PCB 与载板、护罩构成可拔出的接线仓。RJ45 和动力头实际焊在 PCB 上；两个 GMSL 同轴接口固定在金属小支架上，共用模块安装位置，射频信号仍通过同轴，不经过普通 FR4 走线。没有在此处增加 EtherCAT 主站、PHY 或磁性器件。外置盒及 PC 通信架构保持既定方向，本包不设计外置计算机。

## 如何拧紧和拆装

桌夹由左右两根 M12 压紧螺杆向上顶紧，使用 **AF6 长内六角从螺杆下端插入**；交替、小步收紧，使上下压板均匀接触桌面。两側横向 M6/M8 螺钉连接骨架，不用于夹紧桌板。模型显示了真实六角入口和工具方向。尚无经过力标定的安装扭矩，不能把手拧紧等同于额定承载。

1. 先装金属承力骨架、上下软垫、钢压脚及不承力的分体保持罩，再安装桌夹。
2. 盒架朝 +Y（桌内）伸出。盒体检具为 180×150×50 mm，3 kg 是空间/载荷分配值；控制器尚未选定。安装盒体时另配 20 mm 绑带，模型已开绑带槽。
3. 接线仓先在桌外装 PCB、绝缘/接地及接头，再由上方装入后沿开口，以四颗 M4 固定。两颗凹入的 M3 固定其保护罩。
4. 灯罩和灯板先装到前罩背面；两颗 M2×6、0.3 mm 垫圈与 ruthex RX-M2x4 热熔嵌件固定灯板。嵌件外形以原厂 STEP 核对为 Ø3.6×4 mm；当前 Ø3.2 预孔需要打印试片验证热熔工艺。
5. 拆前罩时先拔灯线；拆后仓时先拆后罩，拔掉全部内外线，再松四颗 M4 向上取出。接口护罩宽 129 mm，加垫圈总包络 130 mm；底板开口宽 132 mm，左右各有 1 mm 名义间隙。护罩垫圈位为 Ø8 开边凹孔。

## 数字检查与未关闭项

[几何记录](build/geometry-checks.json)检查每件自制零件的单一有效实体、STEP 重读和封闭 STL。曲面 STEP 体积重读误差阈值为 max(0.02 mm³, 0.001%体积)，不是加工公差。[装配记录](build/assembly-verification.json)检查 15/30/60 mm 三种桌厚、螺钉头/垫圈、长工具和离散拆装位置；[静态交集记录](build/nominal-collisions.json)另存总装结果。刚体检查不含标准件之间和元件之间的全部配对；螺钉只另查头部及垫圈，螺纹啮合按堆叠另算。记录与检查脚本、源模型及实际读入的 PCB 文件散列绑定。

尚待实物关闭：打印变形与热熔嵌件保持力、螺纹/公差、桌板材质和压痕、夹紧力与承载/倾覆、线缆弯曲半径和插头释放手感、RJ45/GMSL 信号完整性、48 V 温升与上电、灯罩亮度与串光。没有完整柔性线束模型；不把直通网口的布线规则通过当作 EtherCAT 或相机链路合格。

[B04-P1 力学计算](../../docs/engineering/base-b04-strength.md)是历史计算证据，P2 的后开口和外罩已变化，不能直接作为 P2 制造/承载放行。[旧 PDF 图册](build/drawings/README.md)也只保留为 P1 检查点；它不与本版 STEP 混用。生产图册需在此轮三维评审后重新冻结。

## 重建

在仓库根目录、安装 CadQuery / trimesh 的 Python 环境中依次运行：

```sh
python engineering/base_b04/build.py
python engineering/base_b04/verify.py
python engineering/base_b04/cad_surface_normals.py
python engineering/base_b04/viewer.py
blender -b --python engineering/base_b04/blender_scene.py
```

先按三个 PCB 子包说明生成各自机械文件；本包直接读取这些原生导出。`build/index.html` 全资源内嵌；本地预览可用 `python3 -m http.server 8769 --bind 127.0.0.1 --directory engineering/base_b04/build`。

嵌件依据：[ruthex RX-M2x4 原厂页面](https://www.ruthex.de/collections/gewindeeinsatze/products/ruthex-gewindeeinsatz-m2-70-stuck-rx-m2x4-messing-gewindebuchsen)。原厂详细 CAD 不作为本项目自制件再发布；总装仅含带尺寸依据的简化外包络。

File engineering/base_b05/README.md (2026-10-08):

<!-- SPDX-License-Identifier: CC-BY-NC-4.0 -->
# B05 底座：历史八件式打印试装候选

**历史版本，已由[B06-COMPACT-02](../base_b06/README.md)取代。** 本文保留当时的分件、孔位及检查范围，不能作为当前底座设计入口；后续底座修改统一在`engineering/base_b06/`进行，见[同源规则](../../docs/engineering/base-authority.md)。

本轮按用户确认的8件方案收敛SHAPE-06。保留魔鬼鱼式连续翼肩、前鼻、独立中央环台与琥珀灯窗；左右后肩甲分别并入翼肩，原横向装甲线改为0.8 mm宽、0.4 mm深的浅槽。内部四组支架与两半底环改为两件一体骨架。造型浅槽不再意味着独立零件。

外罩约 **356×253 mm**，中心环台OD170/ID104 mm、最高Z74 mm，轴心XY(0,75) mm。前鼻保持独立，避免整壳超出220 mm打印床，也避免左右中缝穿过灯窗。后盖独立拆装，环台不承担机械臂负载。

| 自制分件 | 数量 | 约尺寸 XYZ，mm |
|---|---:|---|
| 左/右一体翼肩外罩 | 2 | 各178×187×55 |
| 前鼻外罩 | 1 | 199×74×55 |
| 后部检修盖 | 1 | 151×32×51 |
| 中央装甲环 | 1 | 170×170×16 |
| 透光灯窗 | 1 | 37×5×3 |
| 左一体安装骨架 | 1 | 128×208×55 |
| 右一体安装骨架 | 1 | 118×208×55 |

- [旋转/拆盖/爆炸预览](build/exterior/index.html)：8个自制件＋18螺钉＋18螺母，共44个可视实体。
- [原生Blender模型](build/exterior/ODR-BASE-B05-EXTERIOR.blend)：保留母曲面、分件实体和购买标准件参考。
- [正面](build/exterior/front-three-quarter.png)、[俯视](build/exterior/top.png)、[后侧](build/exterior/rear.png)、[一体骨架](build/exterior/frame.png)：实际模型渲染。
- [八件STL试装包](build/exterior/B05-exterior-fit-prototype.zip)：仅8个自制件，标准件不供打印。
- [网格与床包络检查](build/exterior/print-checks.json)：8/8通过。检查床为220×220×250 mm，XY各留5 mm。
- [名义紧固尺寸检查](build/exterior/assembly-checks.json)：18/18通过。
- [两半骨架表面检查](build/exterior/frame-clearance-checks.json)：0个表面相交三角面对；不检查完全包容、拆装路径或工具可达性。
- [安装接口数据](build/exterior/mounting-contract.json)：本轮孔位、螺母槽和搭接尺寸。

## 简化与装配

自制件由14降至8，标准件由27螺钉/27螺母降至18螺钉/18螺母。外罩固定6颗（每侧3颗）、前鼻4颗、后盖2颗、装甲环4颗、骨架搭接2颗，统一ISO7380-1 M3×10和DIN934 M3螺母。原支架与底环之间的8颗螺钉已取消。

翼肩与前鼻保持0.8 mm名义接缝；各外罩采用0.5 mm浅圆头螺钉座，孔Ø3.4 mm、头座Ø6.6 mm。圆头螺钉有意露出形成装甲细节，螺母槽对边5.8 mm、高2.8 mm，向+Y插入。真实标准件尺寸仍需采购核对，简化螺纹参考不得打印代替标准件。

两半骨架在Y=-8和159 mm处以两处搭接连接。左件带一体定位舌，右件带接收槽；水平与高度名义间隙各0.3 mm，两颗螺钉从上方夹紧到左件内的螺母。搭接定位代替了上一版需要夹具保持底环两半相对位置的做法，实际刚度和装配补偿仍待验证。

1. 先打印孔槽与搭接小样，确定打印补偿；再分别切片8件。
2. 从侧面插入两半骨架的螺母，将定位舌放入接收槽，拧入两颗骨架连接螺钉。
3. 对准骨架上的随形支柱，装左右翼肩与前鼻；检查外罩没有被螺钉强行拉弯。
4. 安装独立后盖，检查插线、拆盖和工具入口。
5. 装中央环台。四根独立支柱穿过薄壳隐藏孔，环台夹紧力不通过薄外罩传递。

这是数字试装候选的装配顺序，尚未经实物执行。透光件固定、灯板安装和完整线缆仍需下一模块设计。

## 打印与集成边界

STL单位为mm；`print-parts/`已平移到正坐标，`stl/`保留总装坐标。8件均闭合、单连通体、正体积、无重复/退化面并满足床包络。最长骨架208 mm，占210 mm可用床长的大部分；切片时须核对支撑、裙边/边沿占用和实际打印机可用面积。

网格检查不检查最小壁厚、自交、支撑、层间强度、收缩或配合公差。骨架虽合为两件，其支柱上的螺母插槽仍可能需要支撑，不能据此声称免支撑打印。建议PETG/ASA无动力试装，灯窗使用透光材料。

本轮骨架仅固定外罩，尚未连接正式承载骨架、桌夹与机械臂法兰；不可装机械臂做带负载动作。旧B04/B05骨架和法兰不能直接套用本轮包络。后部116×56 mm PCB空间、下出线口与灯窗仍为候选空间，RJ45、两路GMSL同轴、独立48V真实接口组件、PCB固定、线缆弯曲半径与应力释放尚未完成集成；[嘉立创接口PCB](../electronics/base-io-b05/README.md)本轮未修改。

原生构造按1微米网格清理，处理重合相反面、无实体体积的单三角薄片及最短高不足1微米的四面体布尔碎片；独立检查器不修补模型。`assembly_checks.py`只检查名义间隙和螺杆覆盖整个螺母高度，不证明预紧力、实物装配或载荷资格。

最新8件候选独立位于`build/exterior/`；上一版14件保留在`history/shape-06/`。已确认概念参考保持在`docs/concepts/selected/`，未混入新候选。

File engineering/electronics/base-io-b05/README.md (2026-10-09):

# 当前版本说明 · 2026-10-09 就地5V修订

当前原生工程包含7个供电元件和13个新增控制器元件；见[CONTROL-01 状态与独立调试](controller/README.md)。当前保存复开后的严格PCB DRC为0，26个实际元件，制造文件以 [b06-io-control01](manufacturing/b06-io-control01/) 为准。检查入口 `controller/check_native.py` 和 `check_routed.py`。旧13元件导出只用于追溯；整套底座尚未生产放行。

以下记录是此次供电修订前的历史基线，供对照；其中6元件、48焊盘、217段线、16过孔及prototype制造包不代表当前板。

# BASE-IO-B05 嘉立创 EDA 迁移工作包

CC-BY-NC-4.0；Required Notice: Odradek — Auromix contributors.

已经在激活后的专业版 4.1.60 客户端完成原生导入、恢复原理图网络、移动 J2/J6，并保存实际可编辑的 [原生工程](base-io-b05/base-io-b05.eprj3)。原 BRI01 保留不变。通过本项目的 MCP→官方 CLI 适配器操作；原理图导入变更弹窗由 GUI 确认。适配器不是厂商原生 MCP。

`migration-input/kicad/` 保留源格式副本。`reports/migration-status.json` 和 `reports/native-relocation-readback.json` 记录当前状态与实际 API 读回；原 KiCad ERC/DRC 结果不能继承到嘉立创 EDA。

PCB 原生坐标以 mil 为 API 单位、Y 向负方向。J2 已移动到 (58,0) mm，J6 到 (42,20) mm；实际 48 个焊盘中 38 个电气焊盘有网络，10 个机械焊盘无网络。板框仍为 116×56 mm。

## 历史阶段：初始无源通路

以下是初始217线阶段的记录，不是当前控制器版数量。

**接口板已完成数字布线与制造导出，整套底座仍未放行。** 2026-10-09先完成48V双外层2.4 mm铜线，再完成8条数据网络、16个过孔和四组等长补偿。保存关闭并重开后，原生DRC为 **0项**；48个焊盘保持不变，34段供电铜线保持不变，整板现为217段线。[实际重开读回](reports/b06-data-reopened.json)及[独立审计](reports/b06-routed-audit.json)记录当前版本。初始83项候选错误未通过放宽规则解决：修正交叉、安装孔禁布区、同网重复钻孔，再重建覆铜并补偿长度。

[PCB打样候选文件](manufacturing/b06-io-prototype/)包含嘉立创原生导出的Gerber ZIP、四个铜层、金属化/非金属化钻孔、16个Ø0.6过孔钻孔、IPC-D-356A电测网表。ZIP CRC及过孔坐标与原生读回一致。仅用于板级打样检查；不能继承为完整底座装配或通电放行。

此板为无磁RJ45被动直通布局，不能据此视作EtherCAT控制器。丝印“DATA 8P PASSIVE”和“B06 IO / ROUTE REVIEW”保留，CHASSIS标识避开J6。机壳屏蔽和RETURN48仍是分离网络。GMSL走独立同轴馈通，不经过普通FR4线路。

本轮机械对照使用B06同源外罩与底架。板框116×56 mm、厚1.6 mm，PCB坐标(u,v)映射总装(X,Y,Z)=(58-u,30-v,24)，API读回先把mil转换为mm并翻转Y。H1..H4分别对应(52,24)、(-52,24)、(-52,-20)、(52,-20)，与底架四个安装孔一致；[原生读回](reports/b06-native-fit-readback.json)保存器件和焊盘坐标。后盖开窗是检修/插拔空间，不能当作接插件承力板；真实插头、锁扣和线束仍须试装。

独立铜箔几何检查：上下供电路径一致，每极每层7个焊盘处于一个连通铜区，两极外层铜最小间距约4.585 mm。假设外层铜35 µm、两层平均分流，中心线模型估算供电回路电阻约4.80 mΩ，10 A约48 mV/0.48 W；20 A约96 mV/1.92 W。**这不是载流额定值**：未包含接插件、过孔桶壁、焊盘扩散、接线和温升。

本轮修正原生物理叠层中mm误作mil的问题，通过GUI导入、保存、重开及原生日志最后记录确认：外铜35 µm、内铜15.2 µm、两侧7628介质0.2104 mm/Er4.4、芯板1.065 mm/Er4.6、铜面上方阻焊0.01524 mm/Er3.8；含阻焊模型总厚约1.6166 mm，采购标称1.6 mm。以[嘉立创官方JLC04161H-7628资料](https://jlcpcb.com/impedance)为工艺目标。接口的“所有物理叠层配置”返回空列表是已保存预设列表，并非当前板的厚度证明；当前配置API也未正常返回对象，验证使用GUI和原生文件当前记录。

八条信号线各使用2个过孔，四组铜线总长度误差小于0.000025 mm（数字坐标结果，不是加工精度）。长度补偿包含非耦合段，**并未验证全路径100Ω阻抗、Cat6、千兆以太网或EtherCAT链路性能**。板级样品需要TDR/协议流量与电源温升验证。

板级阶段不改几何；其后COMPACT-04已抬高PCB至Z24并后移10mm，安装变换以B06当前源为准。真实电源插头宽高已按官方资料复核，但深藏接头的闭盖锁扣可达性仍未闭合，见[插头复核记录](reports/b06-plug-review.md)。下一阶段先验证局部插合基准，再决定是否修改后盖或接口安装位置。

源码：[原生走线脚本](route-power-native.js)只能在激活客户端、指定PCB、零铜线的首次阶段执行，重复执行会拒绝；[独立检查](check_power.py)检查保存重开读回与当前PCB哈希；[审阅图生成器](plot_power.py)仅用于可视化，不是Gerber或制造图。

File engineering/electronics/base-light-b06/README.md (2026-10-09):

# B06 独立 PWM 前灯

用户已确认：程序独立调光、呼吸、闪烁。采用底座IO板就地产生的5V、PWM和RETURN48，经内部GH三芯线连接三路独立限流的琥珀LED灯板，不增加桌下5V线。PWM高电平点亮，断开或复位时47k下拉保持关闭；建议1kHz。同一IO板已加入[STM32灯控候选](../base-io-b05/controller/README.md)和UART命令接口；固件数字测试通过，IO板铺铜DRC已为0，实板和线束仍未闭环，不能作为完整通电放行。

实际原生工程在`../base-io-b05/base-io-b05/base-io-b05.eprj3`，板名称B06-LIGHT-PWM，PCB文档`pcb/PCB1.epcb2`，原理图`sch/Schematic1/P1.esch2`。与IO板共用同一个原生工程和仓库，不维护第二套独立底座。当前板50×14×1.6mm，双面铜，元件全顶面，四个NPTH；保存、复开和原生DRC检查通过。45条线路、8个过孔、12个元件。`manufacturing`为客户端实际导出的Gerber、BOM、贴片坐标、网络、IPC356与STEP；`audit.py`复核实际文件、引脚网络、钻孔、数量和指纹。

J1实际是SMT GH接口；库的封装显示名含CONN-TH，不能按显示名当作通孔件。引脚1=5V_IN、2=PWM_IN、3=GND。采用JST GHR-03V-S线端壳及SSHL-002T-P0.2端子，AWG26–30、线径/绝缘尺寸依JST资料；必须按端子编号查方向，不能按正视左右臆测。外部5V支路建议限流100mA以内，PWM为3.3V/5V逻辑，与底座共地。**不得接入48V。** 5V供电范围暂定4.75–5.25V，点灯典型约17mA；三路470Ω各自限流，保守电流上界约34mA。该上界不代表短路保护或热认证。

LED1–3：LTST-C170KFKT / C284931，605nm；R1–3：RC0603FR-07470RL / C114669，470Ω；R4：RC0603FR-071KL / C22548，1k；R5：RC0603FR-0747KL / C105579，47k；Q1：DMG2302UK-7 / C460977；D1：NSVBAT54HT1G / C179609；C1：CC0603KRX7R8BB104 / C92490，100nF/25V；J1：BM03B-GHS-TBT(LF)(SN) / C161691。采购/贴装以原生导出BOM与贴片坐标为准；未下单。

元件依据：[LiteOn LED](https://optoelectronics.liteon.com/upload/download/DS-22-99-0185/LTST-C170KFKT.pdf)、[Diodes MOSFET](https://www.diodes.com/datasheet/download/DMG2302UK.pdf)、[onsemi串联保护二极管](https://www.onsemi.com/download/data-sheet/pdf/bat54ht1-d.pdf)、[JST GH接头](https://www.jst-mfg.com/product/pdf/eng/eGH.pdf)。GH板端高度4.05mm、插合高度7.3mm；库STEP仅作实际导出尺寸参考，不视为供应商认证模型。

全局机械坐标：STEP本地`(u,v,w)`映射为`(u−25,168.5+v,44.073+w)`，其中STEP v向后为负。板底Z44.073、板顶Z45.673；两颗M2安装孔X±23/Y163.5/Ø2.4，两枚灯窗支撑柱X±17/Y164.5穿Ø3.2 NPTH。GH位于X−5.2/Y158，插合上界预算Z52.973。原生STEP实体进入同一份Blender装配；还需真实线束弯曲、端子压接、透光效果和实物装配验证。

脚本执行顺序：`create-native.js`创建候选板/图→`schematic-native.js`使用完整原生库项重建本新图→`connect-native.js`设置PCB焊盘网络→原生ECO同步→`route_plan.py`与`route-native.js`→原生保存/复开DRC→客户端制造导出→`audit.py`。重建脚本会替换该新灯板的原理图电路，先备份，不能对其他原理图运行。早期50×10报告是历史记录，当前依据为`connected-native-50x14.json`、`routed-native-50x14.json`和`schematic-current.json`。

CC-BY-NC-4.0；Odradek / Auromix contributors。

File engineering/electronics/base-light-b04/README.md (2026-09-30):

# BASE-LIGHT-B04-01 前灯小板

本包把 B04 前灯变成可打开、可检查的 KiCad 小板：**50 × 12 × 1.6 mm、三颗琥珀 LED、四根导线、两处 M2 安装孔**。服务板已有三路限流，本板不增加驱动或电阻。此模块取代旧服务板 BOM 中三个独立 3 mm 黄灯的外观候选；旧服务板原理图与布线未改。

入口：[KiCad 工程](kicad/base-light-b04.kicad_pro)、[原理图](kicad/base-light-b04.kicad_sch)、[PCB](kicad/base-light-b04.kicad_pcb)、[全局坐标 STEP](mechanical/base-light-b04-assembly.step)、[机械接口 JSON](mechanical-interface.json)。全部是原生文件；LED 三维体是按尺寸自建的保守盒形包络，没有仿真光学透镜。服务板和灯盒都不在该 STEP 中。

装配采用前罩 P2 的前鼻位置：相对最初草案整体 +15 mm Y，避开中央领座；原生PCB、孔位和线路未改。

## 位置与光学配合

局部板底原点对应全局 `(-25,235,28) mm`，`x=u−25,y=v+235,z=w+28`。板底 z28、顶面 z29.6。KiCad 采用 `x=u,y=12−v` 的屏幕坐标，不能把其 Y 直接当全局 Y。

| 特征 | 板局部 u,v / mm | 全局 x,y / mm | 含义 |
|---|---|---|---|
| H1 / H2 | (3,6) / (47,6) | (−22,241) / (+22,241) | Ø2.2 NPTH；各轴 R3 禁铜/禁非安装器件 |
| D1 POWER | (13,6) | (−12,241) | 琥珀，+Z 出光 |
| D2 RUN | (25,6) | (0,241) | 琥珀，+Z 出光 |
| D3 FAULT | (37,6) | (+12,241) | 琥珀，+Z 出光 |

选 **Würth 150120AS75000**，官方称 Amber，典型主波长 605 nm。其本体标注 3.2 × 1.6 mm，高度 0.68±0.10 mm；本包 XY 使用 **3.4 × 1.7 mm 规划盒**，Z 使用最大高度0.78加0.10 mm焊料预留，LED 顶部 **z30.48 mm**，距约束 z32 余 **1.52 mm**。3.4 mm 是我们选定的长度规划包络，不冒充厂商单独规定的最大长度。原厂参考焊盘为两块 **1.4 × 1.6 mm、内间距1.6 mm**，中心距3.0 mm；pin1为阴极，位于局部−u。[原厂尺寸及光电数据](https://www.we-online.com/components/products/datasheet/150120AS75000.pdf) pp.1–2。

38 × 6 mm 胶囊窗由底座模型定义在 x±19、y238…244、顶面随 B04-P2 外壳曲面变化，以底座 STEP 中灯罩为准；本模块对应左/中/右三分区。隔光筋、灯盒、光导由底座包负责，需避开三个 LED 盒及安装 R3。**没有均匀发光、亮度或串光合格结论**；三个灯颜色相同，状态靠区域/文字辨认。

## 四线接口与装配

J1 是背面焊线铜盘，不是采购连接器；焊盘尺寸2.5 × 3 mm，v2.5 mm，u为19/23/27/31。按**从元件面沿+u看**的顺序如下；从焊接面看左右会反转，以板上针号及导通检查为准。

| 灯板 J1 | 全局 x,y / mm | 服务板 J3 | 网络 | 线色建议 |
|---|---|---|---|---|
| 1 | (−6,237.5) | 1 | GND，公共阴极 | 黑 |
| 2 | (−2,237.5) | 2 | LED_PWR_A | 白 |
| 3 | (+2,237.5) | 3 | LED_RUN_A | 黄 |
| 4 | (+6,237.5) | 4 | LED_FAULT_A | 橙 |

服务板端采用既有 **XHP-4 + 4 × SXH-001T-P0.6**。该具体触点允许 AWG28–22、绝缘外径0.9–1.9 mm；本模块提出 **26 AWG、外径1.0–1.5 mm** 为线材目标，未选精确线号、工具或最终裁线长度。不得将低插入力型号带 N 的范围混入。[JST XH 原厂目录](https://www.jst-mfg.com/product/pdf/eng/eXH.pdf) pp.3–5。

四线从板背面沿 **−Y** 离开，局部装配预留 **x[−8,8]、y[225,239.5]、z[25,28] mm**。独立 `wire-reservation-only-assembly.step` 只显示这个空间探针，不是实物线束或全程走线证明。焊点、绝缘套管和转弯都应落在这一区域，最终线材弯曲半径及远端路由另核。

顺序：先回流焊LED并检查极性，再从背面焊线并绝缘；在灯盒上单独做线束应变释放；按底座灯盒规定的装入方向，将板装到两孔的支承面，禁止螺钉/压件压LED；最后连接服务J3。拆模块前断开服务J3、释放线束卡持，再拆板。**不能靠铜焊盘承受拉线力**。安装螺钉、支座高度及光导装入路径由底座装配统一检查，不在本板包冻结。

## 电气与亮度边界

服务板的 POWER/RUN/FAULT 分别由 **R22/R14/R20，2.2 kΩ** 限流；该映射已从当前服务板 netlist 和原理图导出复核。5 V、Vf2 V 且忽略开关压降的示例电流为 **1.36 mA/灯**。若实测电源≤5.1 V、电阻−1%、Vf≥0，则每路计算上界2.342 mA；该算例不替代服务稳压器的全温容差测量。

官方亮度是在20 mA测量；不把140 mcd典型值移用到约1.3 mA。样件应依次测三路实际电流、照度/正视可读性及遮罩下串光，再决定是否需要在服务板新修订中调整限流。**本板禁止直接接未限流5 V、12 V或48 V。** POWER仅表示服务板局部5 V，不能判定驱动已停止或整机无电。

## 已核对与待验证

`verification.json` 记录 KiCad **ERC 0、DRC 0、断线0、原理图/PCB不一致0**，以及独立回读的四网十焊盘映射、两孔位置、R3禁布距离和三路上游限流器件。软件检查有默认忽略项，原始列表保留；本包另外解析原生焊盘/导线/过孔及LED包络检查安装区，未用“零DRC”等同实物合格。

`mechanical/verification.json` 记录8实体装配STEP导出重读、有效性/体积/包围盒核对。全局STEP包含板、三LED盒和四背面铜盘；`native-kicad.step` 是另一份直接由 KiCad 模型引用导出的板，使用KiCad导出坐标，**并非全局底座坐标**；其板体仅输出默认1.51 mm介质，不含完整铜/阻焊叠层，不能据此替代1.6 mm板厚契约。`board-only.stl` 是无电板形试装件；打印件不能代替FR4通电板。

Gerber/钻孔为真实工具导出，状态仍为制板审查候选。板厚容差、阻焊/钢网、焊线拉力、夹持紧固、温升、ESD、灯盒实配及光学验收尚未完成。

复现：

```sh
python3 rebuild.py --kicad-python /path/to/kicad/python3 --kicad-cli /path/to/kicad-cli --cadquery-python /path/to/cadquery/python3
```

可另用同时装有CadQuery和PyMuPDF的Python执行 `tools/finalize_review.py`，重做STEP读回、SVG渲染与包内哈希；需再目检新图。

KiCad本次版本10.0.6；脚本不会下载第三方库。`sources.json` 保存官方PDF页码与缓存SHA，官方PDF/CAD不随包分发。`upstream-inputs.json` 保存本次只读服务板输入哈希。

许可证 CC-BY-NC-4.0；署名 Odradek / Auromix contributors。继承仓库许可与非商业使用边界。

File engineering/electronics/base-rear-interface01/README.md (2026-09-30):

# BRI01 physical base interface candidate

CC-BY-NC-4.0; Required Notice: Odradek — Auromix contributors.

Open `kicad/base-rear-interface01.kicad_pro`. The board is a passive, non-magnetic 8P8C straight-through plus separate 48 V power path. SMA adaptors mount mechanically on the shared carrier; they are not RF traces in this PCB.

- `mechanical/parts.json` and `mechanical/base-rear-interface01-assembly.step`: matching 59-part original global-coordinate model.
- `connector-contract.json`: datums, ports, apertures, partially closed mating/cable envelope.
- `routing-plan.json`: actual final routed copper replay; no scratch router items.
- `reports/`: native ERC/DRC and schematic XML; `native-readback.json`: actual pads/routes.
- `fabrication/`: manufacturing review Gerber/drills, not production release.
- `verification.json`, `manifest.json`: checks and file hashes.

See `docs/engineering/base-rear-interface01.md` from repository root for exact prototype limits and reproduction.

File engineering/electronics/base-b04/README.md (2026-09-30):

# B04-SERVICE01

Native routed low-power base service PCB. This is **not the complete robot-base connector panel**: EtherCAT, GMSL, and main actuator power are out of scope and require the separate interface assembly.

Read `../../../docs/engineering/base-b04-pcb.md`. Start with `mechanical/base-b04-assembly.step` for assembly coordinates, `kicad/base-b04.kicad_pro` for native ECAD, and `verification.json` for exact current evidence.

Licensed CC-BY-NC-4.0 under the repository license; Odradek / Auromix contributors. Official component drawings are cited, not redistributed. Gerber/drill files are real exports for manufacturing review; physical, electrical, EMC, thermal and process qualification remain open.

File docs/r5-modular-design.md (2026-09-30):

<!-- SPDX-License-Identifier: CC-BY-NC-4.0 -->
# R5：单驱动四瓣末端与独立七轴本体

本轮依据用户最新参考图和明确修订：四瓣无需独立控制，允许一个电机带动另外三瓣随动；电机尽量收进中央后壳。末端和本体分别设计，通过质量、接口和视觉语言协调。

本页两张图属于深化提案，未因版本较新而自动列为已选图。用户选定的外观参考单独见 [收敛设计图目录](concepts/selected/README.md)。

## 末端形态

单驱动末端外观与中央布置研究

上瓣保留宽肩、折线收腰、较等宽的长灯面和截平倒角端；下瓣采用相同造型语汇但更短、更小。四瓣左右镜像，上下不作中心对称。图中的中央内部仅表达布置意向，不能从生成的齿轮或连杆直接读出可制造尺寸。

发光面本身参与夹持。当前结构研究方向为可更换透明顺应表层、透明承力层、暗色周边和横梁骨架，LED与PCB置于避载腔；实际材料、摩擦、变形、接触温升和寿命需要验证。圆形LED屏保留像素化灯环和方向图案，双鱼眼仍在上下中线分别外倾。画面不代表闭态通过，闭合姿态必须从同版CAD和运动方程导出。

## 本体形态

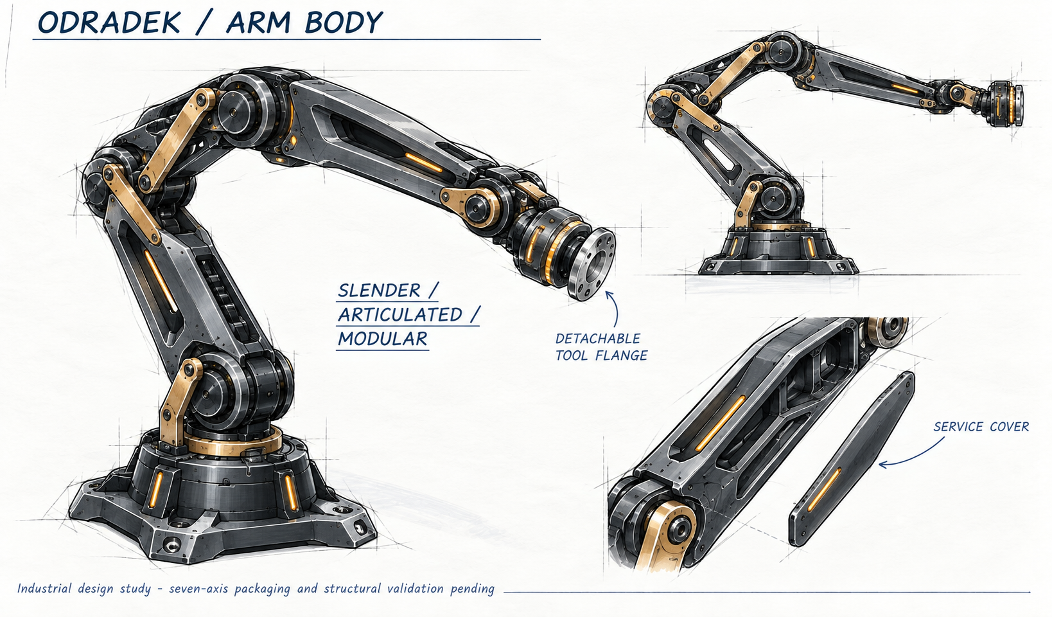
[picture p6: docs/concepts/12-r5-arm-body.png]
七轴本体独立外观研究


本体采用细长主连杆、适度露出的关节层次、浅凹结构面、可拆维护盖和少量琥珀色光。末端拆除后仍应具有完整外观；腕部以短、轻、清楚的法兰接口收尾。生成图中的结构数量不作为七个真实主动轴的证据，实际关节布局以参数模型为准。

2kg指工件净重，另计末端。分开设计不等于把末端重量从本体计算中删除：法兰接口需接收末端质量、质心、惯量和工件六维载荷。约700mm指肩至任务TCP的目标尺度，不能同时把肩至法兰的长度也默认成700mm。概念图不覆盖目前真实关节尺寸、动态线束、承力连接和散热约束。

## 当前架构和权衡

| 项目 | 已确认或当前处理 |
|---|---|
| 本体主动轴 | 7；J7沿末端正面法线带动整头旋转 |
| 末端驱动 | 用户允许1电机＋3瓣mimic，当前首选1主动坐标带动4个瓣关节 |
| 四瓣关系 | 上下可不同速比；真实连杆可能为非线性映射，不预设URDF线性mimic |
| 接触后动作 | 限力夹持；研究分支串联弹性或被动差动，允许先接触瓣让位 |
| 空载能力 | 全闭静止→全开→全闭静止≤1s；持续1Hz热占空未指定 |
| 负载与尺度 | 2kg净工件＋实际末端质量，肩至TCP约700mm |
| 末端质量目标 | 暂争取≤1.5kg，是工程权衡目标，非用户硬指标或已实现值 |
| 接口 | 可拆；EtherCAT执行链、双GMSL/GMSL2同轴、内走线、外置计算 |

少一个主动轴并不自动少一套机械约束。刚性四支联动在第一瓣接触后可能阻止其他瓣贴合；如果增加被动顺应，就需要明确行程、复位、限位和每支最大力。单电机电流只能约束总广义驱动力，不能分别观测四个接触力。

## 本轮工程顺序

先以参考轮廓生成真实上、下指片及透光承力截面；同时综合中央滑块和四支连杆，求解角度、雅可比和死点。随后把二者放到同一装配中检查空手闭合、持物接触、中央光学遮挡和传动空间，再更新惯量、驱动、控制、供电及本体载荷。

[FAST-GRASP01](engineering/fast-grasp-requirements01.md)维护确认输入；[工程基线](engineering/current-baseline.md)区分新路线和历史快照。原P16分支不能满足1s要求，现归档。现有中央屏及其电路可能复用，旧四片PCB是否保留必须服从新灯面轮廓、载荷路径和空间。

本页两张图由内置image_gen使用参考生成，完整提示词与边界见[末端](concepts/11-r5-single-drive-head.prompt.md)和[本体](concepts/12-r5-arm-body.prompt.md)。它们是工业设计研究，尚非制造图、完整运动验证或2kg样机资格。

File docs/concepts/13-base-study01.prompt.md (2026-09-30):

<!-- SPDX-License-Identifier: CC-BY-NC-4.0 -->
# BASE STUDY 01 图稿来源与提示词

- 工具：内置 image_gen，初稿生成后进行一次局部修改；未使用 CLI/API 回退。
- 初稿参考：[机械臂视觉语言](12-r5-arm-body.png)、[四瓣头视觉语言](11-r5-single-drive-head.png)。它们只约束风格，不用于继承旧底座的尺寸、夹具或负载结论。
- 最终资产：[13-base-study01.png](13-base-study01.png)。
- 初稿输出：exec-2f4fbb66-0633-411f-a457-6de53b8c4de1.png；修改输出：exec-6f93a77d-c8b7-4697-a9b7-560d98e04879.png。
- 图稿用途：底座外观候选比较与布置讨论，不是 CAD 导出的多视图或制造图。

## 初稿提示词

```text
Use case: stylized-concept.
Asset type: one landscape industrial design comparison board for the Auromix Odradek desktop robotic pet project.
Primary request: create THREE alternative BASE designs only, with practical hidden desk-edge clamp and rear concealed wiring, to help the owner choose the visual direction. This is an industrial design sketch, not a manufacturing drawing.
Input images: Image 1 is the EXISTING ARM visual-language reference: slender graphite structural forms, chamfered edges, champagne-metal joints. Do NOT copy its large bolted floor-style foot. Image 2 is the approved FOUR-PETAL HEAD visual-language reference: angular broad shoulders, tapering truncated ends, warm amber light, left-right symmetry. Use their style only; do not redraw the head or whole arm.

Layout: a beautiful editorial industrial design sketch board, white/off-white paper, landscape 3:2, high resolution, thin graphite construction strokes, restrained marker shading, crisp accurate perspective. Top title in clean readable typography: "ODRADEK / BASE STUDY 01". Three evenly spaced columns A, B, C. Each has a large front-three-quarter view of its base mounted at the BACK EDGE of a pale wood desktop, viewed from the user side. All use identical viewpoint, desktop, scale and the SAME short vertical first-joint collar with a short cut-off lower-arm stub; omit the rest of the arm. Each base has a visually compact but credible volume beneath the collar, NOT an impossibly wafer-thin motor housing. The tabletop itself is a small isolated rectangular segment, not a room scene. In normal top views the clamp mechanics and connectors are concealed.
A label: "A  圆角椭圆". Broad low oval footprint, gentle soft sides, restrained machined chamfers, quiet companion character, one tiny amber status accent only.
B label: "B  收腰盾形". A refined left-right-symmetric faceted shield footprint, FRONT toward user tapered to a BLUNT rounded nose, restrained concave side waist, broad REAR for recessed connector access, a few broad graphite planes with rounded edge transitions, champagne detail at the collar. Visually the most balanced sci-fi companion. No sharp spikes, no excessive greebles.
C label: "C  窄长鞍座". A narrow side-to-side, elongated FRONT-TO-BACK saddle footprint, body flowing from the joint collar to a slim covered rear cable spine that reaches the table edge. It must visibly differ from A and B in plan silhouette. Not a long tail hanging beyond the desk.

Under each large view, include a small monochrome TOP-VIEW silhouette thumbnail to make the three footprints immediately comparable.
Bottom third: TWO larger detail illustrations for candidate B only, with clean callout leaders:
1) "隐藏式桌夹" — simple side cutaway at the actual desk edge: upper load-bearing chassis resting on top of table; structural bridge goes around OUTSIDE the desk edge; lower padded clamp jaw presses UP onto the UNDERSIDE of tabletop; accessible captive adjustment screw underneath within a slim shroud. Show the desk as solid wood in section. Do NOT place any clamp screw, rod or wire THROUGH the desk. No desk drilling, suction cups, exposed large clamp handle in normal view. Separate shell from metal structural chassis by subtle shading. This is packaging intent, not a claimed verified mechanism.
2) "后盖与下行线束" — rear three-quarter detail of B with only a small rear service cover lifted away by an arrow; connectors mounted on a removable RECESSED interface plate: one rectangular network-port placeholder for EtherCAT, two small circular coax placeholders for GMSL, one distinct power-connector placeholder. Connected cables turn downward with visibly gentle loops and strain relief, gathered into one flexible sleeve routed down BEHIND the desk edge next to the clamp, never squeezed between desk and clamp pads. The shroud hides cables in normal view. Use only two short extra text labels: "可更换接口板" and "线束避开夹持区". Do not draw an external controller box, CPU, display, keyboard or computer.

Materials: satin charcoal graphite shell, darker recesses, sparse champagne metal, tiny warm amber accents. Light, poised, sophisticated mechanical pet, refined science-fiction mecha family. No full light rings on the base, no large illuminated faces or logo, no sharp fins, no four exposed mounting feet, no tabletop bolt holes, no unnecessary vents or fan grilles.
Text at bottom, exactly and legibly: "外观与布置候选 · 尺寸、夹持承载与线束空间待验证".
No fake dimension numbers, no 2kg performance badge, no equations, no CAD certification language, no watermarks. Sparse annotation with generous white space. The board must visually convey how hidden clamp and rear wiring fit at the desk edge without pretending structural validation.
```

## 局部修改提示词

```text
Use case: precise-object-edit. Edit this existing Odradek BASE STUDY 01 industrial design comparison board. Preserve the overall layout, the A/B/C labels, the three main rendered base designs, all materials/colors, the two left top-view thumbnails, and the lower-left hidden clamp illustration exactly.
Make ONLY these three localized clarity corrections:
1. The small C TOP VIEW currently has its amber FRONT pointing left. Redraw only this small top-view thumbnail rotated/reoriented so the base's long axis is VERTICAL on the page, amber rounded front toward BOTTOM of page and elongated rear cable spine toward TOP. Match the front-to-back orientation used in the A and B top views; keep C narrow across the page and elongated front-to-back. The large C three-quarter illustration stays unchanged.
2. In the lower-right rear access detail, the Chinese label "可更换接口板" must point at the recessed connector-carrying metal PANEL still attached inside the base, not at the floating plain cover. Reposition its leader accordingly. Add the short clear Chinese label "可拆后盖" pointing at the detached plain outer cover. Preserve generous whitespace, no crossed annotation leaders.
3. In that same lower-right detail only, show four connected cable positions on the actual panel: ONE rectangular network connection, TWO small circular coax connections, ONE larger distinct DC power connection, with each cable visibly originating at its corresponding connector. Remove the phantom extra row of plugs below the visible sockets. Route those four cables gently DOWN behind the desk, past a strain-relief clamp and into the common sleeve. Keep cables OUTSIDE the wood and OUTSIDE the clamping contact surfaces. These are generic packaging placeholders, not rated connector specifications.
Keep all other pixels and artwork as close as possible. Retain the bottom disclaimer exactly: "外观与布置候选 · 尺寸、夹持承载与线束空间待验证". No new dimension annotations, performance claims, logos or watermark.
```

## 图稿检查与剩余限制

三种主要外形、统一臂根视觉语言、桌边夹持示意及后部下行线束已经呈现。修改版将接口面板和外盖的标注分开，并调整 C 俯视缩略图的朝向。

图稿仍不是同一参数模型的投影：C 的俯视缩略图没有完整对应大视图的后部长尾；后仓线端与插座不构成逐一精确的插接说明，不能据此清点实际接口或判断弯曲半径。候选选择以各列大视图和方案文字为准。夹具强度、桌面接触压力、后盖拆卸空间、线束余量与旋转关节走线均待真实结构验证。

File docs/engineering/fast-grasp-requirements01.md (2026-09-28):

<!-- SPDX-License-Identifier: CC-BY-NC-4.0 -->
# FAST-GRASP01：发光面夹持与一秒空载开合

用户明确：**正常夹持是灯片的主功能，灯片发光面本身就是夹持面；快速张合属于附加能力，但空载全闭→全开→全闭须不超过1秒。** 接触物体后转入限力夹持，不要求带物体完成空载全行程。此确认替换“选低速间歇推杆还是连续呼吸”的旧需求理解。

## 确认输入与设计判据

| 项目 | 当前要求 | 对工程设计的约束 |
|---|---|---|
| 夹持功能 | 2kg工件净重，末端自重另计 | 驱动须满足持续夹持，而非只达到瞬间峰值力矩；对象尺寸、摩擦与外部加速场景必须列明 |
| 抓取接触面 | 发光灯片面本身作为夹持面 | 透光接触表层和承力基体共同设计，不能只用独立尖端小垫替代整个面。LED/PCB不作为主载荷路径 |
| 速度 | 空载完整往返≤1.0s | 从静止全闭开始，经全开再回到全闭静止；先按每程0.5s分配，无额外停留，曲线必须满足速度、加速度、驱动能力和碰撞约束 |
| 接触动作 | 接触后限力夹持 | 快速空载轨迹遇到物体时退出位置快移并受控减速；检测延迟、允许接触冲击与力限制待计算/验证，不能由电流设定直接声称指面力已知 |
| 自由度/外形 | 四瓣可单电机联动，上长下短、左右镜像 | 用户取消四个独立驱动的要求，允许1主驱动＋3瓣mimic。保留参考图的折线肩部、宽灯面与截短端部，避免纯三角片与周边突出电机。原109°/122°只作历史角域起算 |
| 工件与接触分担 | 盒体、瓶罐50–120mm；接受一对相对灯片主夹持 | 用户2026-09-28确认优先紧凑可靠，另外两片同步但可不接触。优先正向同步，不要求多级被动差动；两主接触的力与抗转能力须重算 |
| 主体与接口 | 7轴本体、约700mm、EtherCAT、双GMSL/GMSL2、内走线、外置计算 | 新指驱动供电、通信节点数、重量和转动惯量必须重新并入主臂与线束，不能沿用旧8从站/P16电源预算 |

“≤1秒”描述完整往返能力；持续每秒循环的占空、次数和热稳态尚未指定。正常持物时不能为了灯光或呼吸表达主动改变夹持力。表达可使用LED亮度变化或空载动作。

## 当前路线处置

P16-50-256-12-P分支的现机构单程约17.5～19秒，无法满足新要求，**停止作为主末端驱动路线推进**。其CAD、数学和电气记录留作历史比较；不继续把其低速演示作为目标能力。既有七轴本体、相机、中央屏和灯板可以作为下一轮的输入，但可复用性需结合新发光承力面确认。

| 已有成果 | 下一轮用途 |
|---|---|
| P16/HEAD03/HEAD04、DRV8874四路控制及12V电源研究 | 历史分支；不可作为一秒末端采购或运行配置 |
| HEAD-MASS04指片几何积分与独立角域计算 | 提供初始指片惯量/姿态，剔除P16机构及将改动的承力面后重新计算 |
| FPL01灯板、CD-PCB01中央屏及可拆杯座 | 可复用电子/安装候选；FPL是否继续保留需看接触层厚度、承力/散热及闭合关系 |
| 七轴关节/实体连接、肩部加强候选 | 本体结构研究继续；新头重、质心与反力确定后重算，旧载荷结果不自动成为新头的资格证据 |

下一轮按“保留外形的发光承力面 → 单驱动四瓣联动和接触顺应 → 一秒往返运动/夹持需求 → 中央隐藏伺服与传动 → 四瓣总装”推进。选择时同时校核持续零速扭矩、速度—扭矩能力、编码器、失电行为、反射惯量及电热限制；不以最大空载转速和堵转扭矩拼成不存在的工作点。

发光面方案至少应明确透光可更换接触层、支承跨度、主受力骨架、光学腔、LED/PCB防压空间及受压后的闭合间隙。接触层的摩擦、磨损、污染、透过率及局部温升需实测。四瓣单驱动不能独立分配四个夹持力；抓持模型要处理接触点分配、摩擦锥和物体力矩平衡。按最新确认，一对接触后即可进入夹持，另外两片不必继续贴合；局部顺应仍服务于误差、限力及接触稳定性，不再为任意矩形四面贴合而强制加入差动。

上下瓣的mimic关系可由机构实现，不预设1:1角度。四连杆/凸轮约束可能非线性；URDF的线性mimic不能替代真实运动学。当前保留4个可见瓣关节，首选1个主动广义坐标，不再把旧“4DOF末端”当作强制输入。

本体与末端分开开发，风格保持协调。本体仍以2kg净物体和约700mm为目标，末端自重不作零处理；接口分别给末端质量、质心、惯量与外载荷。工程上暂以整头≤1.5kg作为轻量化争取目标，尚非用户确认的重量规格，也不是已实现值。

此页为确认后的设计输入，不是新驱动已选完、1秒硬件已实现或制造发布。

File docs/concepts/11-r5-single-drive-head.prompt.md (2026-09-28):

# R5 single-drive head — prompt and provenance

Generated using the built-in `image_gen` tool. Reference: user-supplied four-petal industrial-design image (2026-09-27), used for silhouette and visual language. The reference itself is not redistributed here.

The result is an appearance and packaging concept. It does not define a proven linkage, exact motor dimensions, actuator count inside the generated cutaway, manufactured contact skin, or a collision-free folded state. Actual single-drive kinematics and force transmission are separate engineering work.

## Prompt

Use case: stylized-concept.
Asset type: industrial design concept sheet for the Auromix Odradek robot end-effector, not a manufacturing drawing.
Input image 1 is the user's chosen appearance reference. Closely preserve its exact visual identity, silhouette proportions, articulated narrow roots and four shaped illuminated petals. This is a new sheet referencing the image, not a traced screenshot.
Primary request: show a compact practical luminous four-petal gripper, with ONE concealed central rear actuator mechanically driving all FOUR petals through short linked roots. No four peripheral motors. The entire light-facing surface of each petal is also the gripping surface, with a thin transparent compliant sacrificial skin supported by a structural perimeter and backing; electronics recessed behind the load path. The end-effector is detachable from the robot wrist.
Invariants: two LONG upper petals have the reference's distinctive bent/stepped shoulder near the root and long slightly tapered wide luminous face with blunt clipped outer ends. Two SMALL lower petals are short faceted blade-like panels with a shoulder and chamfered/truncated tips, NOT plain triangular spikes. Left-right mirror symmetry, larger upper pair and smaller lower pair. Central round amber pixel display, ring drawn with pixels and small directional glyph. Two fisheye lenses on the vertical centerline above and below, subtly tilted up/down. Dark graphite structural frame, restrained warm metallic linkage details and amber light. Do not turn the head into a bulky ball or add outside cylindrical actuator housings.
Composition: landscape white warm-gray industrial design sketch board. Large three-quarter FRONT OPEN hero on the left occupying 65%, very close to the reference's silhouette. On the right an elegant SIDE section concept sketch of the same head showing a slim central rear housing, ONE internal motor/gear envelope and a proposed common sliding collar or linkage driving the roots. Shade only proposed internals lightly; do not invent precise tooth counts, dimensions, or imply kinematic validation. A small isolated detail below shows the light-facing gripping surface with transparent skin and metal edge, not a separate black finger pad. Do NOT depict a falsely perfect fully closed pod, folded geometry not yet solved.
Style: professional industrial design sketch illustration, crisp fine black pen, light blue-gray marker volume, restrained construction lines, realistic mechanical joints, ample white space, matching provided aesthetic. No photoreal background, no watermark and no brand logos.
Only text, clean readable English: top 'ODRADEK / SINGLE-DRIVE HEAD'; views 'OPEN / FORM REFERENCE', 'CENTRAL DRIVE / PACKAGING STUDY', detail 'LUMINOUS GRIP FACE'; small bottom note 'Concept only - linkage, clearance and force validation pending'. Do not print performance numbers, dimension lines, motor model names, or claim manufacturing readiness.

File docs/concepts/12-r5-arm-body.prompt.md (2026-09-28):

# R5 arm body — prompt and provenance

Generated using the built-in `image_gen` tool. Input: `11-r5-single-drive-head.png`, used for material and appearance continuity only. This sheet is a separate body form study. Generated joints, linkages and service routing are illustrative; the image does not prove seven independently actuated axes, structural capacity, cable clearance or a manufacturable assembly.

## Prompt

Use case: stylized-concept.
Asset type: separate industrial design exploration sheet for a seven-axis desktop robot arm BODY, part of Auromix Odradek.
Input image 1 is STYLE AND MATERIAL REFERENCE ONLY: the selected four-petal gripper. Do not attach this head to the arm and do not copy its face onto any arm joint. The arm body and head are designed separately, joined by a detachable wrist flange.
Primary request: a slender, agile science-fiction mecha-inspired seven-axis practical fixed-base arm, matching the reference head's graphite metal, refined facets, exposed small structural details and restrained amber accents. Approx700mm scale and2kg net object are project targets, not performance claims to print. The body should look balanced and physically plausible, not a massive industrial welding arm and not a decorative toy.
Architecture intent: base yaw, shoulder pitch, an upper-arm roll articulation, elbow pitch, a forearm roll articulation, wrist pitch, and final axial tool-flange roll. Two long slim structural links with purposeful internal ribs or shallow recessed channels, short well-articulated wrist, compact flared anchored desktop base. Keep distinct structural link proportions and joint housings proportionate to loads. Use asymmetry of link profiles and negative space to suggest agility, NOT large shoulder armor, huge cylinder motors, bulky backpack boxes or lots of exposed cables.
Composition: wide warm-white sketch board with a large three-quarter bent-arm hero left, ending in a plain blank detachable wrist flange, no gripper attached. Right side smaller side silhouette in a reaching pose of the same body plus a detail of tapered link shell and flush removable cable service cover. Give the form enough breathing room. Do not invent cable paths around impossible sharp corners; indicate internal routing only as a light conceptual ghost line. Both views consistent mechanical design.
Style: professional industrial design sketch illustration matching the supplied image, crisp fine black pen strokes, light blue-gray marker, realistic dark graphite/steel surfaces, few warm-metal mechanical pivots, subtle narrow amber status details. Slender engineered sci-fi character. No photo background, no human, no weapons, no watermarks, no full mechanical dimensions.
Only text: top 'ODRADEK / ARM BODY'; hero 'SLENDER / ARTICULATED / MODULAR'; detail 'SERVICE COVER'; wrist 'DETACHABLE TOOL FLANGE'; small bottom note 'Industrial design study - seven-axis packaging and structural validation pending'. Avoid printing invented model numbers, verified payloads or speed numbers. This is a new form study, not CAD or manufacturing evidence.

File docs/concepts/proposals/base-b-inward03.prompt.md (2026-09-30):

<!-- SPDX-License-Identifier: CC-BY-NC-4.0 -->
# B03 内收盒架：出图与检查

日期：2026-09-30。使用内置 image_gen 编辑，未使用 CLI/API fallback。

## 输入与变更

- 原图：[B02 自设计底座](base-b-custom02.png)，生成前已读取。
- 用户要求盒架向桌内收；随后澄清“贴墙”允许走线空间，并明确保留后沿夹装、允许夹体所需小间隙。
- 本版只调整底座的盒架、后仓维护与靠墙布置；保留已选 B 外形以及 B02 自设计骨架方向。
- 输出：[base-b-inward03.png](base-b-inward03.png)，1536 × 1024。
- 首稿侧视误留旧竖盒，造成同一视图两个盒体，已弃用；第二次编辑去掉旧盒及附件、修正桌后缘和墙线。项目仅收录第二稿。
- 本图是待确认结构提案，未覆盖 selected 目录的已选外形参考；[设计说明](../../base-design-study01.md)维护当前边界。

## 视觉检查与限制

已查看第二稿：三个视图均只表达一个横置盒体，右下盒体位于桌板下方、螺杆的桌内侧；旧桌后竖盒已移除。右下朝左为向桌内/朝使用者，朝右为墙；取盒箭头朝左，工具箭头位于夹紧螺杆下方，墙与夹体之间有必要后缝。原 B 盾形外罩、小琥珀灯和金属臂根风格保持。上方开盖为维护方向标注，不代表已完整绘制开盖运动。

这些检查只针对画面表达。各视图不是同一 CAD 的投影，螺杆横向/纵向位置、淡画远侧螺杆、反力桥和托盘挂臂遮挡仍为示意，未形成可读出的精确实体关系。不得从图测量后缝、板厚、盒体尺寸、线缆弯曲或工具余量，也不能凭图确认夹紧受力路径已成立。后续需用尺寸模型核对整个螺杆行程、扳手转动、取盒、上盖/插头、散热与腿部空间。

没有开展 CAD 干涉分析、结构计算、加工验证或实物承载测试。

## 首稿提示词

```text
Use case: precise-object-edit.
Edit target: attached ODRADEK B02 custom base board.
User correction: the desktop may sit close to a wall. A small rear allowance for the clamp and wiring is acceptable; strict zero-gap flush is NOT required. The CONTROLLER HOLDER AND BOX MUST EXTEND INWARD UNDER THE TABLE, never hang out behind it.
Make a B03 revision of the SAME custom base concept, preserving the B shield waist, blunt rounded front, graphite surfaces, small amber indicator, champagne accents, arm root, paired C cheek metal load frame, top plate, lower reaction bridge and TWO underside clamp screws. Retain the custom design, no branded clamp or PC mount.
Critical geometry:
Define FRONT / TABLE INTERIOR as LEFT in the lower-right SIDE view, rear edge as RIGHT. A light neutral wall is a vertical line beyond the rear edge on the far RIGHT. Show a small visible gap between table rear and wall, labelled "必要后缝" with no number. Only the thin fixed clamp spine and protected wiring occupy that allowance. No box, rack, outward-opening lid, or protruding cable loop may extend toward the wall.
Replace the old vertical controller behind the edge with a FLAT HORIZONTAL controller enclosure and low-profile U cradle, ENTIRELY UNDER the desktop footprint toward LEFT / interior. Custom fixed hanger arms turn INWARD and support the cradle from below, bolted to the FIXED clamp frame, never attached to clamp screws or pressure feet.
Keep the controller and solid tray area farther INBOARD than the two clamp screws, leaving an unobstructed vertical Allen-key/tool corridor directly BELOW each screw near the rear edge. Side hanger arms route around those corridors. In the side view, the screw is near the right/rear and the flat horizontal box is to its LEFT / inside. Do NOT put the box directly below the screw. Preserve two non-rotating pressure feet contacting desk underside and upper load plate pads contacting desk top.
Maintenance: box withdraws horizontally toward FRONT / LEFT from its cradle after releasing a small separate retaining screw/stop, no sliding rails or complex latch. Draw a short inward/front arrow. Keep clamp screws untouched when removing box. Ventilation and connectors face sideways or front/inward, not toward the wall, with visual vent clearance.
Rear wiring BAY remains at the rear of the top shield but its small cover is accessed from ABOVE, not swung outward toward wall; plugs recess sideways/downward within the bay. Route cable bundle through the fixed thin rear channel, then turn inward under desk to controller; no giant bend behind table, no cable passing through wood.
Composition: one consistent three-panel landscape sheet. Left large hero three-quarter view showing shield base on desk and horizontal controller cradle entirely underneath toward interior, use cutaway/transparent strip of desk if necessary to make geometry legible without moving the box outside the desk. Upper right shell-off fixed metal frame and inset inward holder attachment, show exactly two clamp screws. Lower right clean readable SIDE LAYOUT with desk extending left, wall right, small rear gap, horizontal inward controller to left of clamp screws, Allen key entering below screw, box removal arrow toward left. Side layout is the priority: obey physical front/back directions. Do not reproduce the old vertical outboard box anywhere.
Style: industrial design sketch illustration on clean white paper, precise pencil and restrained marker shading, light wood desk, large clear views, no engineering dimension numbers, no certified load, no final manufacturing implication.
Text exactly: title "ODRADEK / B03"; subtitle "内收盒架 · 靠墙布置";
panel labels "外观与内收盒架", "固定骨架与托架", "桌边布置";
short labels "向桌内收", "工具通道", "上方开盖", "必要后缝", "向前取盒";
footer "布置提案 · 后缝、尺寸与承载待验证".
Avoid: vertical tower box outside rear edge; shelf projecting toward wall; box obstructing clamp screws; invented third screw; desk drilling; suction; motorized clamp; fresh shape alternatives; giant cable loops; claims of zero rear clearance.
```

## 定向修订提示词

```text
Use case: precise-object-edit.
Edit target: the attached B03 inward-cradle design board.
Critical correction: the LOWER RIGHT SIDE LAYOUT accidentally contains TWO controller boxes, including the OLD VERTICAL BOX against the wall. That is WRONG. There must be EXACTLY ONE horizontal controller, entirely under the table to the LEFT/interior of the clamp screws.
Keep the title, left hero view, upper-right frame view, colors and shield design unchanged. Redraw ONLY the lower-right panel labelled "桌边布置" to a clean, simple side elevation:
- Desk extends from left and ENDS at the inside of the fixed C-shaped clamp rear spine. No continuation of wood beyond the rear spine, no extra wood block toward the wall.
- Wall is a vertical light grey line at far right, with a visible modest gap beyond the outermost fixed spine/cable cover, labelled "必要后缝". This gap contains NO external controller, NO shelf, NO tall vertical bracket.
- EXACTLY ONE horizontal rectangular low-profile controller sits below the wood and to the LEFT of the clamp screws. Its U cradle faces inward and is supported by side hanger arms attached to the fixed frame; these arms are outside the screw tool corridors. Do not show a solid tray bridging underneath the screws.
- Delete ENTIRELY the old rightmost vertical vented controller, all its old retaining brackets and the cable loop that fed it. Replace with blank paper/air between the thin fixed rear spine and wall, and open air below it.
- At the C-clamp, one near screw and a faint far screw press upward against the table underside. Tool arrow vertically upward below near screw; Allen key stays clear of horizontal controller.
- Cable path confined to a thin channel on the fixed spine, then turns LEFT under the desk into the ONE horizontal controller. It must not turn down to any vertical box, and must not pass through wood.
- Horizontal box removal arrow points LEFT and says "向前取盒".
- Simple, legible side diagram takes priority over intricate mechanical detailing; do not draw a second computer or outboard holder.
Preserve the labels "桌边布置", "必要后缝", "工具通道", "向前取盒". Preserve footer "布置提案 · 后缝、尺寸与承载待验证". No new alternative designs, no numerical dimensions, no claim of zero rear clearance.
```

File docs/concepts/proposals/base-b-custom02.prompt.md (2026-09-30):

<!-- SPDX-License-Identifier: CC-BY-NC-4.0 -->
# B02 自设计底座：出图与检查

日期：2026-09-30。使用内置 image_gen，未使用 CLI/API fallback。

## 输入与范围

- 用户最新要求：撤销现成桌夹/托架总成的采购拼装限制，授权自行设计。
- 外观依据：[已选 B 收腰盾形](../selected/base-b-shield.png)，已先读取原图。
- 输出：[base-b-custom02.png](base-b-custom02.png)，1536 × 1024。
- 内容：同一提案的外观与下挂盒、拆壳金属骨架、桌边侧视；没有新增 A/C 造型分支。
- 当前只是沿 B 继续深化的结构构想，存放于 proposals，不覆盖 selected 中的原参考。
- 完整设计说明：[底座 B](../../base-design-study01.md)。

## 视觉与结构意图检查

已逐图查看生成结果：

- 保留收腰盾形、钝前端、圆润边缘、石墨大切面、少量金色及前部小琥珀灯。
- 拆壳图表达左右两侧金属夹体、上板和下横梁；两个螺杆位于桌下，向桌板底面施压。
- 桌边视图用一实一淡的螺杆表达前后可见性，不解释为增加第三个夹紧点。
- 下挂盒有底托和侧向挡件，图中表达独立支架连接；这是未选盒体的空间占位。
- 六角工具箭头位于盒体前方、螺杆下方，表达需要保留工具入口。
- 标题、三个视图名和布置提案说明可读。

限制：右下虽标“桌边剖面”，实际为示意侧视/局部透视，不是按剖切规则或同一 CAD 导出的制造剖视图。原图中的螺杆头、压垫连接、板件转角、螺栓孔、盒架遮挡关系与线缆弯曲尚非精确几何；不能据画面确认接触、装配可达性或 GMSL 弯曲半径。后仓盖开启和盒子侧向取出路径没有完整展开，须在后续布置模型验证。图中有金属层叠视觉，不据此锁定板厚或实体材料。

结构审阅提出并已写入说明：两侧板需金属横向连接，上板需真实桌面保护垫，盒架不得阻挡两个螺杆的全行程工具入口，插接区与夹具运动区分开，盒子独立取下，先用金属板件分件组装。未开展载荷计算、CAD 干涉、有限元、打印试装或带载试验。

## 原样生成提示词

```text
Use case: stylized-concept, reference-guided industrial design.
Reference image: the supplied ODRADEK B shield-shaped base board is the authoritative appearance reference. Continue ONLY that B silhouette, no alternative styles.
Task: make one landscape industrial design sketch sheet for a CUSTOM-DESIGNED desktop robot base, hidden desk clamp, and independent underslung controller holder. It is a proposed architecture, not a manufacturing drawing. Preserve the compact waist-shaped shield shell, blunt rounded front, dark graphite large facets, pale champagne-metal accents, small amber front indicator and matching slim robot arm root. Improve visual integration using bespoke load-bearing metal parts; no branded monitor clamp, no off-the-shelf PC rack, no bulky hand knobs.
Three panels of ONE consistent design:
1. Left hero, about 45% of sheet: three-quarter view at a flat wooden desk rear edge. Show the small shield base above the desk with only the lower arm root, plus a thin vertical rectangular external controller volume hanging BELOW the rear desk edge on a compact custom holder. The controller is a plain graphite placeholder, not a selected computer. Discreet vents face outward, no brand or invented screen. Keep the desk top readable and the lower mounting visible; adequate room between clamp tooling and holder.
2. Upper right: shell removed, same assembly. A metal top load deck supports the arm root and directly bears on protective desk-contact strips underneath. Two spaced rigid C-shaped side cheeks, one on each side of the central wiring channel, run around the rear desk edge and bolt to a lower reaction crossmember. Top deck, rear spine and lower bridge connect the two cheeks into a rigid metal assembly; plastic outer shell carries no loads. Exactly TWO vertical socket-head clamp screws go through the lower bridge, each with a captive non-rotating swivel pressure foot touching the UNDERSIDE of the desktop. The load deck touches the TOP of the desktop. Clearly show the tabletop BETWEEN the upper pads and lower pads. Tightening tool access is from below/inboard of each screw, clear of the box.
3. Lower right: simple side section or side cutaway, table extends toward LEFT and its rear edge is RIGHT. Show upper metal load deck, C cheek wrapping the edge, lower bridge, one visible upward pressing screw with its pad, the opposite screw faintly behind. In a separate path behind the clamp, a fixed rear spine extends DOWN to a detachable U-shaped bottom cradle and two short hanger cheeks supporting the controller. The holder bolts into the FIXED rear spine, not the clamp screw, moving pressure foot, or cosmetic cover. Box can be removed sideways without loosening the desk clamp. Route a bundled cable in the central stationary rear channel from recessed rear connector bay down to controller, away from screws, pressure pads and tool access. Show a short dashed path for an Allen key below the screw, not through the box.
Visual priorities: consistent same shield in all panels, credible continuous metal load path, two screws total, controller genuinely supported from below, accessible fasteners, rounded desktop-facing edges, clean slim pet-robot aesthetic. Large uncluttered views, white paper, graphite pencil contours and controlled marker shading, pale wood desk, restrained amber/gold. No numeric sizes, no rated loads, no blueprints implying final engineering.
Text exactly: title "ODRADEK / B02"; subtitle "自设计底座 · 结构构想"; panel labels "外观与下挂盒", "金属承力骨架", "桌边剖面"; short callouts only "承载上板", "夹紧螺杆", "独立盒架", "中央线槽", "外置盒占位"; footer "布置提案 · 尺寸与承载待验证".
Do not copy the old single clamp arrangement. No quick-release latch, no motorized clamp, no suction cup, no desk drilling, no extra full robot arm or gripper, no alternative A/C concepts.
```

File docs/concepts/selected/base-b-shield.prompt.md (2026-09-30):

<!-- SPDX-License-Identifier: CC-BY-NC-4.0 -->
# B 收腰盾形单方案图：整理记录

日期：2026-09-30。使用内置 image_gen 编辑工具，未使用 CLI/API fallback。

- 来源：[13-base-study01.png](../13-base-study01.png) 中的 B 方案。
- 目的：按用户要求把已选外形单独归档，去掉 A/C 候选，保留 B 的外观、俯视、桌夹和后仓布置示意。
- 输出：[base-b-shield.png](base-b-shield.png)，1536 × 1024。
- 性质：AI 编辑摘编，不是逐像素裁切，也没有新增结构定型。
- 视觉检查：只出现 B；四幅视图及中文标题可读；收腰盾形、钝前端、石墨色切面、圆润边缘与小琥珀灯延续原参考。完整 A/B/C 图未修改。
- 限制：桌夹和线端仍为原有意向，接口插接关系、线束弯曲与装配未验证；最新要求的桌下外置盒托架尚未绘入；不据此读制造尺寸。
- 末端参考图仅移动文件，字节与原图一致；其旧独立驱动标注在目录说明中标明已被后续要求取代。

## 原样提示词

```text
Use case: precise-object-edit.
Edit target: the attached Odradek BASE STUDY 01 board. The user has selected option B only and wants selected drawings stored separately from other candidates.
Primary request: make a B-ONLY archival presentation board from the existing artwork. Retain the exact design identity and industrial design sketch style of B 收腰盾形. Remove A and C completely. Do not invent a new design.
Composition: a clean four-panel board containing ONLY the four existing B views: the upper-centre B three-quarter view, its B top view, the lower-left B hidden desk clamp side view, and the lower-right B rear wiring cover view. Rearrange these for comfortable reading with white space. Preserve shape, relative proportions, colors, materials, joint root, shield waist, softened edges, amber small indicator, existing screw-clamp visual, and rear cover; no new controller box or bracket. The purpose is to isolate the already-selected appearance.
Title exactly: "ODRADEK / B 收腰盾形".
Labels exactly: "外观", "俯视", "隐藏桌夹", "后部接线仓".
Footer exactly: "外形方向已选 · 结构与尺寸待验证".
Avoid A and C, additional alternatives, new hardware, dimensions, claims of manufacture readiness, or approved engineering. Keep all four B views faithful to the reference. The clamp and wiring are only historical layout illustrations, not resolved hardware.
```

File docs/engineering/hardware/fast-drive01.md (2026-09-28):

# FAST-DRIVE01 — 中央单伺服与四瓣联动候选

SPDX-License-Identifier: CC-BY-NC-4.0  
Attribution: Odradek — Auromix contributors (https://github.com/Auromix/odradek)

本轮按最新输入采用 **1 个中央后置电机、四瓣机械联动**。灯片发光面同时是夹持面；空载全闭→全开→全闭不超过 1 s，接触后转限力模式。2 kg 是工件净重，末端自重另外计入机械臂负载。原四电机、P16 推杆及其 12 V 电源研究保留历史记录，本研究不修改或复用其驱动原理图。

**推荐先以 FAULHABER `3274G024BP4 + 32GPT HT 50:1 + IE3-1024 L` 和 `MC 5010 S ET` 做旋转主轴原型；主轴 180° 对应上下瓣暂定 109°/122°。** 这是一条有公开电机连续工作曲线和齿箱功率边界可核查的候选。`AK70-10 KV100` 单台集成伺服为另一条采购候选；直接电机加微型滚珠丝杆为机构减重备选。三者都尚未取得“2 kg 发光面夹持、热平衡、失电保持”的整机验证。

电机放在中央后壳，传动向四根指轴分配；不在四瓣外缘各放一个电机。外部计算机仍可负责规划；头内 MCU/ESC 或外置伺服控制器只承担执行接口。头总质量力争 ≤1.5 kg 是本轮设计目标，**尚未达成，也不是用户确认的额外硬指标**。

## 1. 先定义同一个主动坐标

令 `s=0…1` 为开合进度，暂用 `q_upper=109°s`、`q_lower=122°s`；真实零点/开闭方向由新机构定义。上下瓣不同长度、接触顺序与外形不能推导出相同传动比。旋转主轴 `θ=βs` 时：

```text
τmaster = Σ τfinger,i · dqi/dθ
Jmaster,fingers = Σ Ji · (dqi/dθ)²
对于非线性映射，还包含 Σ Ji · f'i(s) · f''i(s) · sdot²。
轴向滑环 x=Ls 时：Fslider = Σ τfinger,i · dqi/dx。
```

每程 0.5 s 采用五次 rest-to-rest 曲线 `s=10u³−15u⁴+6u⁵`，`u=t/0.5`。其最大 `sdot=3.75/s`；速度、加速度端点为零，端点 jerk 非零，实际控制若要求更平滑的 jerk 过渡须重新核速度余量。两程合计 1 s 无端点停顿。已有 [FAST-KIN01](../fast-finger-kin01.md) 提供独立数学推导；本轮 [计算脚本](../../../engineering/electronics/fast-drive01/calculate.py) 独立复算虚功、惯量和样例接触值。

| 中央轴行程 β | 主轴峰速 | 50:1 电机峰速 | 66:1 电机峰速 | 对 32GPT HT 连续输入 7000 rpm 的判断 |
|---:|---:|---:|---:|---|
| 90° | 56.25 rpm | 2812.5 rpm | 3712.5 rpm | 速度可行，主动端夹持扭矩较大 |
| 120° | 75 rpm | 3750 rpm | 4950 rpm | 速度可行，80 mm 接触臂的法向项已达 7.551 N·m |
| **180°** | **112.5 rpm** | **5625 rpm** | 7425 rpm | **50:1 优先；66:1 超过连续输入上限** |
| 360° | 225 rpm | 11250 rpm | 14850 rpm | 这两种速比均不适用该曲线 |

本轮选的是 **HT 50:1，精确速比 50.0**；不是另一个系列的 49:1。180° 下，上/下瓣与主轴的线性角比为 0.605556 / 0.677778。这只是待合成机构的目标映射，不是已经画成可装配凸轮、四连杆或齿轮。

## 2. 两条精确执行器候选

| 项目 | A：分体伺服＋行星减速器 | B：集成机器人伺服 |
|---|---|---|
| 明确型号 | `3274G024BP4`，原厂 article `3274.00001`；`32GPT HT 50:1`；`IE3-1024 L`；`MC 5010 S ET` | `AK70-10 KV100`，订购选项 **Driver Board = YES** |
| 数量 | 各 1，四瓣共用 | 1，四瓣共用 |
| 电压 | 电机名义 24 V；驱动电子 12–50 V、电机端 0–50 V 是控制器范围，不是该 24 V 绕组的持续过压许可 | 产品名义 24/48 V；本轮比较 24 V 点 |
| 连续工作依据 | 电机额定 158 mN·m / 8420 rpm，22°C 且 Rth2 降 50%；齿箱三级 7.4 N·m、14 W，两者须同时满足 | 产品表额定 8.3 N·m / 148 rpm @24 V；尚缺明确零速持续热条件 |
| 峰值 | 齿箱间歇 10、峰值 14 N·m；电机堵转数不能当持续夹持 | 峰值 24.8 N·m，不能当持续夹持 |
| 测速/位置 | 数字 Hall＋1024 线 ABZ 差分增量编码器，测电机轴 | 一个 14 bit 内环编码器；表中外环编码器为空 |
| 原生通信 | EtherCAT，支持 CSP/CSV/CST 等 | CAN/UART，需要另做 EtherCAT↔CAN 执行桥 |
| 驱动电流 | MC5010 连续输出 10 A、峰值 30 A，S2 最长 3 s；3274 额定电流 6.88 A | 产品额定/峰值 7.2/23.2 A，原文单位 ADC；不能直接等同相电流 RMS |
| 质量 | 电机 325 g＋齿箱 230 g＋编码器典型 13.5 g＝**568.5 g 下界**；MC5010 ET 另 270 g | 当前精确产品页 **621 g**，含驱动候选 |
| 外形 | 齿箱 Ø32±0.1；电机＋齿箱 L1=127.4±0.8 mm。加编码器后的本体约 144.2 mm、加标准轴伸约 165.2 mm，后两项只是组合估算 | 官方二维名义 Ø89×50.25 mm，未取得整机外形/接插件最大公差包络 |
| 制动/失电 | 未选择已验证的保持制动器 | 未选择制动器；0.48 N·m backdrive 参数不是保持额定 |

来源：[3274 数据表](https://www.faulhaber.com/fileadmin/Import/Media/EN_3274_BP4_DFF.pdf)、[3274 精确订货页](https://eshop.faulhaber.com/en/3274G024BP4/3274G024BP4)、[32GPT HT 数据表](https://www.faulhaber.com/fileadmin/Import/Media/EN_32GPT_HT_FCH.pdf)、[50:1 订货页](https://eshop.faulhaber.com/en/32GPT-HT-50-1/32GPT-HT-50-1)、[IE3-1024 L 数据表](https://www.faulhaber.com/fileadmin/Import/Media/EN_IE3-1024L_DFF.pdf)、[MC5010 数据表](https://www.faulhaber.com/fileadmin/Import/Media/EN_MC5010S_DFF.pdf)、[AK70 精确产品页](https://www.cubemars.com/product/ak70-10-kv100-robotic-actuator.html)、[AK70 二维图](https://www.cubemars.com/data/cms/202602/ak70-10-robotic-actuator-2d-drawing.pdf)。

FAULHABER 原厂组合表明确包括 3274/32GPT HT 和 MC5010；齿箱须带电机供货。上述分项不是已经存在的完整总成订货串；法兰、轴端、编码器、出线选项、最终订单号和组合图仍须确认。MC5010 ET 图示本体最大约 115.5×75.5×45 mm，不含配对插头。它适合先放台架/外部控制盒，头内放置会显著侵占质量与体积；外置后又需要沿臂布置相线、Hall 和差分编码器线，不能宣称现有内走线已容纳。

CubeMars 的[官方系列概览](https://www.cubemars.com/robotic-power-solution.html)与当前精确产品页曾分别给出 521 g / 621 g；本轮用 621 g 做预算，等待受控型号确认。产品表惯量 753.4788 g·cm² 未标明参考轴，本轮不把它当电机转子惯量乘 10²。官方产品链接的负载曲线图片未取得可审阅读数，因此 **不声称已从曲线证明 B 的零速持续能力**。其驱动手册的 18–52 V/20 A/60 A 是对应板卡参数，不能替换电机额定。[AK 驱动手册 V1.0.18](https://www.cubemars.com/data/cms/202605/ak-series-driver-manual-v1-0-18-for-ak-2-0-robotic-actuator.pdf)

## 3. 为什么 A 可以继续，但还不能标 2 kg 夹持合格

3274 原厂 p1 连续工作区域图按 **22°C 环境**区分完全隔热与导热安装。实际核读其零速隔热边界约 **140–145 mN·m**，这是图上估读范围，不是受控公差最小值。158 mN·m 是散热条件改善 50% 的额定点，不能直接移到封闭头壳的静止夹持工况。5625 rpm 附近空载运动的本轮电机需求仅约 25–27 mN·m，位于原厂连续曲线内侧；这仍只涵盖已经建模的惯量和损耗假设。[电机曲线与条件，p1](https://www.faulhaber.com/fileadmin/Import/Media/EN_3274_BP4_DFF.pdf)

| 当前单主轴模型，180° / 50:1 | 复算结果 |
|---|---:|
| 历史四片 `finger_rotor` 总质量 | 0.639234 kg |
| 四指折到主轴的惯量 | 0.000354586 kg·m² |
| 电机＋齿箱输入＋编码器折到主轴的惯量 | **0.012510 kg·m²** |
| 峰加速度 | 72.55197 rad/s² |
| 四指重力力矩绝对值合计上界，折主轴 | 0.073905 N·m |
| 空载主轴输出力矩上界 / 输出功率上界 | 0.099631 N·m / 0.943686 W |
| 电机峰力矩上界，动态齿箱效率假设 0.50/0.65/0.77 | 26.68 / 25.76 / 25.28 mN·m |
| 已计旋转件峰动能，单程中点 | 0.892746 J |

齿箱输入惯量包含小齿轮，196 g·mm² 是目录最大值；编码器磁环另 0.08 g·cm²。计算把电机惯量放在电机侧，不错误地再除齿箱效率，也不把电机加速扭矩全部算成输出轴外载。新连杆、同步轮、凸轮、弹簧预紧、线缆与密封摩擦尚未加入。动能可能在减速时部分回到母线，但实际回生量由损耗、驱动模式和电路决定；它不是电源吸收能力证明。不得继续套用旧 P16 的供电预算。

夹持先用**四接触均衡、μ=0.4、竖直静载系数 2、切向摩擦力臂 30 mm**作显式例子。每瓣法向力 24.5166 N，切向力 9.80665 N。下表法向作用线力臂必须由新“灯片面夹持”结构重新量取；图中较长的灯片不代表法向力臂一定等于灯片全长。

| 法向力臂 | 主轴法向力矩分量 | 法向＋切向同向＋指体重力上界 | 理想无损电机静止扭矩 | 若实测静止传递系数 κ=0.65，所需电机扭矩 |
|---:|---:|---:|---:|---:|
| 40 mm | 2.5170 N·m | 3.3461 N·m | 66.92 mN·m | 102.96 mN·m |
| **60 mm** | **3.7756 N·m** | **4.6046 N·m** | **92.09 mN·m** | **141.68 mN·m** |
| 80 mm | 5.0341 N·m | 5.8631 N·m | 117.26 mN·m | 180.40 mN·m |
| 100 mm | 6.2926 N·m | 7.1216 N·m | 142.43 mN·m | 219.13 mN·m |

定义 `κ = 实测输出静止力矩/(50×电机实际静止力矩)`；此处 0.65 **只是假设敏感性**，不是厂商提供的静态效率。原厂 ηmax=0.77 是运动效率最大值，不能替代 κ 的测量。60 mm 工况若以 0.140 N·m 作为电机试验预算，则至少需要 κ≥0.6578；实际散热和热平衡仍要测。μ=0.2 时 60 mm 工况已超过齿箱 7.4 N·m 连续上限，不能只提高电流。完整 μ/力臂扫描在 [contact-sensitivity.csv](../../../engineering/electronics/fast-drive01/contact-sensitivity.csv)。

因此，本页当时优先把有效接触臂设计在 **40–60 mm 的可验证区域**，保留片面完整发光与前端造型，并给电机金属导热座；不能为了满足数表把尚未实现的力臂当事实。**本页原“两瓣只作降额”口径已被2026-09-28确认替代：用户接受一对灯片主夹持，2kg净工件目标仍保留。** 同样每瓣法向上限下，理想摩擦承载约减半，因此须用[TWOCONTACT01](../r5-twocontact01.md)重算，不能把本页四接触旧条件直接作为新两瓣抓取资格。

32GPT HT 还有 **14 W 连续输出功率**边界。在 4.6046 N·m 工况中，连续转速最多约 29.03 rpm；不能把 7.4 N·m 与 112.5 rpm 同时宣传为连续工作点。快速空载与接触慢速/静止保持必须是不同控制模式，接触减速阈值与柔顺要覆盖检测延迟和惯性。

## 4. 旋转同步与轴向滑环的取舍

**旋转主轴优先原型：** 50:1 输出经单独双支承主轴驱动四路凸轮/拉索/连杆。上/下分支形成不同映射，每个分支串入可测的弹性行程，或通过有行程限位的差动均衡器分配接触。驱动电流只能测总广义力，不能知道某一片已压到上限；建议至少分支位移/触碰观测，必要时每片薄型力传感。刚性 `mimic` 用于空载运动学，接触后的柔顺状态需要更多被动坐标。

不能把普通圆盘四个等长拉杆画成“已实现 109°/122°”机构。下一步必须输出真实 `q_i(s)`、Jacobian、奇异位形/死点、拉索最小弯曲与松弛处理、支承载荷、差动最大偏移和弹性力上限；并证明四片完整闭合/打开与先后触碰的可达性。现有单刚体四接触假设只给所需力的示例，不证明 wrench closure。

**轴向滑环备选：** 电机旋转丝杆、滑块驱动四支连杆，可更直接地设置轴向串联弹性元件；不用 P16 成品推杆。以 50 mm 滑环行程、2.5 mm 导程为例，五次曲线峰速 187.5 mm/s、电机 4500 rpm。上述 60/30 mm 接触臂例子含指体重力需 289.31 N，理想丝杆输入 0.11511 N·m；以 0.140 N·m 电机试验预算反推静止传递系数至少 0.82225，尚未有该实际组合保证。

有可追溯原件候选：Thomson `SRT0825X280` 丝杆原料＋`KGF-D-0825-RH-M-EE` 法兰滚珠螺母，8 mm 直径、2.5 mm 导程，螺母体 Ø16 g6、长 18 mm、法兰外径名义 28 mm；目录动/静载 2.1/2.2 kN。**这不是端部已加工、支承已装配的完整执行器订货号**；工作长度、端部轴肩、推力轴承、联轴器、反转预紧、润滑和允许转速仍需设计/受控数据。目录载荷不能直接当寿命验证。50 mm 行程＋18 mm 螺母的活动轴向区域至少 68 mm，另外还需限位、支承和防撞余量。[Thomson 目录 p3–5](https://www.thomsonlinear.com/downloads/screws/Miniature_Metric_Ball_Screws_bren.pdf)

3274 电机轴向负荷原表仅 5 N @3000 rpm，不能承接几百牛的丝杆推力；滚珠丝杆必须有独立轴向支承。30 mm/5 mm 导程在相同例子中仅理想扭矩已约 0.3837 N·m，直接驱动不合适；不能看到 1350 rpm 就认为轻松。滚珠丝杆可回驱，不构成天然自锁。丝杆路线可去掉 230 g 行星减速器，但净减重必须扣回丝杆、导轨、推力座与制动保持件；未纳入新机构 CAD 前不作为主线已选。

## 5. EtherCAT、保持与供电边界

| 主线选择 | EtherCAT 站数与控制路径 | 需要新增的执行接口 |
|---|---|---|
| A：单 MC5010 S ET | 7 个 RH＋1 个中央伺服＋1 个 HEAD IO＝**9 站** | EtherCAT 时序/ESI与设备状态机；输出侧回零或绝对观测；分支接触检测；制动接口 |
| B：单 AK70 CAN | 7 个 RH＋HEAD ESC＝**8 站**，HEAD MCU 再控制 1 个 CAN 伺服 | CAN 收发器、实时桥、同步与超时状态；现有 HEADCTRL02 不能宣称已包含这一驱动 |
| 旧四伺服 | 12 站仅历史对照 | 不再作为四瓣独立约束 |

MC5010 的制动控制输出表示可连接保持制动器，**不表示已经装有制动器，也不代表 STO 认证**。A/B 都没有本轮确认可装配的断电保持方案；低速摩擦、backdrive 数字与软件 disable 不能代替。角度锁住也未必保持柔性接触面的夹力。机械止动/制动器需要针对中央轴至少 4.60 N·m 示例载荷、冲击与夹力衰减重新选型；历史 0.06 N·m 输入制动器在 50 倍理想折算也仅 3 N·m，不可直接沿用。

候选 A 需要独立重新预算的 **24 V 电机电源支路**；旧 12 V P16 电源、四 DRV8874 和 HEAD-POWER01 只是历史分支。控制器接受的电压范围不等于可以直接并入当前 48 V RH 总线。需在运动惯量与接触减速实际测量后确定供电限流、母线电容、回生吸收、故障关断和逻辑保持；本轮没有假设外置电源可以反向吸收能量。

## 6. 头部尺寸与质量的真实余量

| 已知部分，尚缺新载体等 | 总质量下界 |
|---|---:|
| A 电机/减速器/编码器＋历史四片实体 | 1.207734 kg |
| 上一行＋MC5010 放在头内 | **1.477734 kg** |
| B 单 AK70＋历史四片实体 | 1.260234 kg |
| C 直接电机/编码器＋历史四片，尚未加丝杆/支承 | 0.977734 kg |

这些数都缺新接触片表层、中央屏、相机、承力主轴/分支、壳体、线路、法兰和紧固件；旧指体也只是质量参考，新造型会改变它。“下界”指预算还未计齐零件，不是含制造公差的严格实重下限。A 的外置驱动布置更可能接近 1.5 kg 目标，但仍只有约 292 g 留给所有其余头部件，不能声称已满足。B 轴向较短、直径较大，中心可隐藏单台，却需要重审上下鱼眼、中央屏背部与机构体积。C 质量余量较好，轴向长度和支承复杂度较高。

22/26 mm 轻电机不再为“四台驱动”继续扩展选型。已查的 2264 BP4 是 140 g、额定 59 mN·m：50:1 传动的本轮 60 mm 接触例即使理想无损也需 92 mN·m，不宜仅因轻就替代 3274；更大速比又会增加电机峰速和反射惯量。[2264 原厂表](https://www.faulhaber.com/fileadmin/Import/Media/EN_2264_BP4_DFF.pdf)

## 7. 本轮交付与下一步准入条件

原厂资料、页码、SHA 与尚未知字段见 [sources/fast-drive01.json](../sources/fast-drive01.json)。第三方 PDF/HTML 仅保存在本地工作证据目录，不作为原创文件再发布。Thomson PDF 经官方网页读取，直接下载返回 403，因此源记录明确无本地文件 SHA；没有补造哈希。采购候选分项见 [candidate-bom.csv](../../../engineering/electronics/fast-drive01/candidate-bom.csv)。

复算：`python3 engineering/electronics/fast-drive01/calculate.py`。输出 [budget.json](../../../engineering/electronics/fast-drive01/budget.json)、旋转/丝杆扫描表和 manifest；核验了单位转换、曲线端点/极值、坐标变换下动能一致、虚功，以及与独立 FAST-KIN01 接触法向例子的数值一致性。

优先继续 A 的中央隐藏驱动机构设计，同时保留 C 作为减重对照。进入带电夹持前，应关闭以下具体缺口：真实发光面接触几何与摩擦/耐磨层；四分支柔顺及限力；新映射下反射惯量和全开合干涉；电机安装散热/零速热平衡；输出侧力标定与掉电保持；完整订货组合与含插头包络；24 V 电源/回生路径。上述是下一阶段工作项，不妨碍先做无电、无载机构样件，也不把当前候选标成制造或承载放行。

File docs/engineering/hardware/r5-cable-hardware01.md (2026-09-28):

# R5-CABLE-HARDWARE01：两级差动钢索条件选型

**建议继续集成一套升级组合：叶索 Sava 2037 + SP3106，二级索 Sava 2050 + SP4125。** 在下述弯曲强度代理、原厂寿命优化建议和已验证终端的条件下，它们覆盖每叶 50 N、二级 100 N 的中档筛选；75 / 150 N 不覆盖该筛选。真实允许张力仍为 **TBD**，不能把表中的条件上限写成组件额定工作载荷。线径全公差、压接保持力、锚点、轴隔套和反复弯曲寿命没有闭合。

本包只研究钢索、滑轮、终端。输入拉点为各瓣局部 `A=[R+13,0,−12] mm`，`R=31…91 mm`，沿 `−er` 拉动闭合；`head Z<−17 mm` 只是初始可布置区域。没有证明整条钢索可穿过、叶索不会松弛、三只动滑轮可装入或整头抓持通过。原始数据、公式和结果分别在 [catalogue-data.json](../../../engineering/electronics/r5-cable-hardware01/catalogue-data.json)、[calculate.py](../../../engineering/electronics/r5-cable-hardware01/calculate.py)、[budget.json](../../../engineering/electronics/r5-cable-hardware01/budget.json)。

## 一套主候选与失败对照

| 位置 | 裸索精确 Part / 网页 Item | 名义线径 | 最小破断力 B | 单位长度质量 | 滑轮 Part / Item | 槽根径 / 外径 | 名义 D/d |
|---|---|---:|---:|---:|---|---:|---:|
| 叶索，主候选 | 2037 / 103017 | 0.9652 mm | 711.716 N | 3.423 g/m | SP3106 / 101874 | 27.0002 / 31.750 mm | 27.974 |
| 二级索，主候选 | 2050 / 103024 | 1.1938 mm | 1201.020 N | 8.185 g/m | SP4125 / 101884 | 31.750 / 38.100 mm | 26.596 |
| 历史较小叶索，仅作比较 | 2032 / 103015 | 0.8128 mm | 533.787 N | 2.381 g/m | SP3088 / 101876 | 22.479 / 27.178 mm | 27.656 |

三条钢索均为 **302/304 不锈钢、裸 7×19、Commercial**，不是带 `SN` 后缀的包塑索。主候选数据来自 [2037](https://www.savacable.com/stainless-steel-cable-bare-7x19-commercial-1329)、[2050](https://www.savacable.com/stainless-steel-cable-bare-7x19-commercial-1347)、[SP3106](https://www.savacable.com/sp-series-pulley-nylon-prec-dble-shld-bb-2390)、[SP4125](https://www.savacable.com/sp-series-pulley-nylon-prec-dble-shld-bb-2393)。较小组合来自 [2032](https://www.savacable.com/stainless-steel-cable-bare-7x19-commercial-1321)、[SP3088](https://www.savacable.com/sp-series-pulley-nylon-prec-dble-shld-bb-2389)。网页列项不代表已核库存、交期或价格。

## 张力区间：分别核算弯曲段和终端

Sava 的 [滑轮设计指导](https://www.savacable.com/sava-expertise/pulleys-design-information) 建议 7×19 裸索槽根径至少为线径的 25 倍；其弯曲强度表在 `D/d=20` 时给出 0.91，在 30 时给出 0.93。本包对 26–28 的名义比值取较低档 **η_b=0.91**，不臆造插值。这个数是破断力折减指导，不是传动效率。

Sava 历史设计指南 DG1007 的寿命优化建议为直索最小破断力至少为工作张力的 10 倍。本研究进一步把它施加到各薄弱处的破断代理：

`B_system,proxy = min(B η_b, B η_terminal, F_anchor, F_other)`

`T_screen = B_system,proxy / 10`

其中 `/10` 是本研究采用的寿命筛选，不是用户规定、法规强制系数，也不是十倍寿命保证；它与动力学中工件重力因子 2 分开。给定 25/50/75、50/100/150 N 已是条件张力，本包不再次乘 2。压接处和绕轮段在不同位置，默认取最小值，不能机械相乘；也不按经过几只轮把 η_b 乘几次。所有试验、冲击和预紧造成的实际峰值仍要进入 `T`。

| 组合 | 条件张力 N | `B η_b / T` | 达到 10× 所需终端保持率下界 `10T/B` | 本轮结论 |
|---|---:|---:|---:|---|
| 2037 + SP3106 | 25 / 50 / 75 | 25.91 / 12.95 / 8.64 | 35.13% / 70.25% / 105.38% | 低、中档有条件可用；高档失败 |
| 2050 + SP4125 | 50 / 100 / 150 | 21.86 / 10.93 / 7.29 | 41.63% / 83.26% / 124.89% | 低、中档有条件可用；高档失败 |
| 较小 2032 + SP3088 | 50 | 9.71 | 93.67% | 中档已因弯曲代理失败 |
| 较小 2037 + SP3106 用作二级 | 100 | 6.48 | 140.51% | 中档失败 |

若终端实测保持率足够，主候选的弯曲筛选上限为 **64.766 / 109.293 N**。仅作灵敏度演示，假定终端保持率 85%，独立薄弱处模型上限为 **60.496 / 102.087 N**；85% 不是本候选压接的已证保证。若额外采用保守乘积 `η_b×0.85`，上限则为 **55.051 / 92.899 N**，二级 100 N 不再覆盖。这个乘积是另加的假设，必须写明，不能混入主表。完整逐项数据见 [load-scenarios.csv](../../../engineering/electronics/r5-cable-hardware01/load-scenarios.csv)。

## 受控尺寸缺口不能由网页小数位补齐

旧 Sava 原厂署名 [DG1007 设计指南](https://cdn.thomasnet.com/ccp/00571837/377158.pdf) 由 Thomasnet 托管；本地保留 SHA 与页码，原 PDF 不入项目库。其 SP 图有公差，当前官网只有名义值，两者尚未证明为同一受控版本。

| 尺寸 | SP3106 | SP4125 | 证据边界 |
|---|---:|---:|---|
| 轴承孔，旧图 | 4.7625 ±0.0127 mm | 6.3500 ±0.0127 mm | 官网前者写 0.188 in，旧图为 0.1875 in；可能四舍五入，未证实 |
| 槽根径，旧图 | 27.0002 ±0.508 mm | 31.750 ±0.508 mm | 当前官网同名义值 |
| 外径，旧图 | 31.750 ±0.508 mm | 38.100 ±0.508 mm | 包装应留公差及额外运动间隙 |
| 轴承厚度 / 尼龙厚度 | 6.350 / 5.5626 mm | 7.1374 / 7.1374 mm | 旧图二者各 ±0.254 mm |
| 槽 R，参考值 | 0.889 mm | 1.270 mm | 不能据 R 大于钢索半径宣称有足够包覆接触 |
| 官网最大适配索径 | 1.6002 mm | 2.3876 mm | 旧图分别 1/16、3/32 in，有显示精度差异 |

旧指南的 `.036… .065 in` 裸索外径容差为 `+ .008 / −0 in`。若把它和旧根径负偏差组合，主候选最差 `D/d=22.674 / 22.364`，**未达到 25**；名义满足不等于全公差满足。若沿用旧根径负公差，要保证 25 比，实际最大线径必须不超过 **1.059688 / 1.249680 mm**。反过来使用旧钢索最大径，所需实际最小槽根径为 **29.210 / 34.925 mm**。这是供下一轮实物测量/受控图审查的约束，不是把当前商品筛成一个新 SKU。旧容差是否仍适用于本批产品未知。

两主候选均无加长内圈版本。SP3106 名义轴承每侧突出尼龙 0.3937 mm；旧最差宽度组合且假定居中时仅 0.1397 mm。SP4125 名义突出为 0，旧最差甚至可能由尼龙突出。**必须独立设计只接触轴承内圈的隔套、支承叉和轴向保持件。** 内圈承压台阶外径、实际居中/轴向偏移、安装配合、轴承内部型号和轴静承载证据均未取得，故没有给出虚构通用垫圈/销轴型号。原创 [包络图](../../../engineering/electronics/r5-cable-hardware01/component-screen.svg) 和 [mechanical-interface.json](../../../engineering/electronics/r5-cable-hardware01/mechanical-interface.json) 不包含这些零件。

## 滑轮载荷、速度与寿命

SP 是尼龙轮配精密双防尘盖单列球轴承，网页标为 ABEC3；这不等于轮体全尺寸为 ABEC3。三个型号官网 `Load Rating=90` 没写单位；旧同型号表明确为 **90 lbf = 400.340 N，500 rpm 基准**，并列出恒载、恒速、正常润滑/安装条件下 2500 h 平均寿命语境。当前版本一致性待确认。不能读成 90 N、最大转速 500 rpm 或保证寿命 2500 h。旧表的寿命换算排版不足以建立可靠公式，本包不自行补指数。

同张力、转向角 `β` 的轴载为 `P=2T sin(β/2)`：180° 时，叶索三档为 50/100/150 N，二级三档为 100/200/300 N。中档二级轴载 200 N 小于 400.340 N 的旧额定基准，**只是一项比较**，不是对往复载荷、叉座或尼龙压配保持的寿命证书。两侧不等张力应取矢量和；动滑轮自身质量与惯性、预紧、偏航和轴向分力另计。严禁把钢索 T 直接作为 180° 动滑轮的轴载。

固定滑轮无滑动时近似 `n=60v/[π(D_root+d)]`。对 0.225 / 0.450 m/s 两个显式线速场景，叶轮为 153.66 / 307.32 rpm，二级轮为 130.44 / 260.88 rpm。它们是场景值，**没有证明当前差动的各轮就是这个线速**。对同向坐标下两条平行索支路，动轮中心速度 `v_c=(v1+v2)/2`，`|ω|=|v1−v2|/(D_root+d)`；必须从实际路由求支路速度，不能把载体径向速度直接套到每个轮。制造商没有在已读资料中给出本工况允许最高 rpm、温度和逆转寿命。

旧指南的 7×19 寿命曲线明确针对包塑型号，不能给本包裸 7×19 批次读出循环次数。一次开合循环不等于每个索段一次弯曲，折返/反向弯曲数量由实际路径决定。钢索的结构就位伸长、弹性伸长、迟滞和滑轮摩擦需测量；不采用实体钢棒 `Eπd²/4` 代替索刚度，也不假定 η=1。持续 1 Hz 占空未确认。

## 终端与打样工具

| 用途 | 精确候选 | 尺寸 / 搭配 | 尚未闭合 |
|---|---|---|---|
| 叶索标准长环套 | **7030C**, Item100509 | 锌镀铜；名义索径 .027–.038 in；L=7.112 mm；旧图 Ls 为压后参考 | 2037 落在名义上端；实际 OD 与模腔窗口待验证；当前网页工具 NA |
| 二级标准长环套 | **7047C**, Item100514 | 锌镀铜；名义 .039–.054 in；L=11.176 mm | 当前页工具 T188；旧图支持 T185-B 或 T188-1，需确认现版工艺 |
| 单套打样工具 | **T185**, Item101904 | 旧图叶索用 D 腔，二级用 B 腔；铜/黄铜短批试制用途 | 手柄压力、成品压接尺寸、拉脱载荷未实测；不替代工业压接工艺 |
| 叶索护环，保留候选 | **AN100C01**, Item100632 | 适配 .015–.046 in；内开口 A=4.826 mm，B=6.350，槽宽 D=2.3622 mm | 小开口与保证强度用销径要求之间无公差余量，不能直接配 M4 销后称全强 |
| 二级护环，保留候选 | **AN100C03**, Item100633 | 适配 .046–.078 in；A=8.890，B=17.8562，D=2.3622 mm | 销、完整环眼包络及载荷保持仍未知；不能仅凭 `Mil Spec` 名称推额定载荷 |

来源：[7030C](https://www.savacable.com/zinc-plated-copper-loop-sleeve)、[7047C](https://www.savacable.com/zinc-plated-copper-loop-sleeve-1866)、[T185](https://www.savacable.com/crimping-tool-light-duty)、[AN100C01](https://www.savacable.com/stainless-steel-thimble-commercial)、[AN100C03](https://www.savacable.com/stainless-steel-thimble-mil-spec)。完整 A–F 原厂参考值存于数据 JSON；这些不是完整成品端环的包围盒。

原厂 [样件工具说明](https://www.savacable.com/products/accessories-prototype-kits-page) 把 T185 环套保持完整索破断力作为正确实施时的设计目标，同时要求样件拉力验证。**本项目没有实际终端保持率。** 不用短套 `C1`，不用将约 50% 的包塑球头/螺纹端头数据转移到本环套，也不把不锈钢环套的 85% 数据转移到所选锌镀铜环套。

旧原厂端环图规定保证破断力相关的 `P≥5d`、从承压点至套的 `D≥2.5P`。对名义 2037，5d 已等于 AN100C01 的 4.826 mm 开口，尚无销与孔的装配、公差余量；带护环时有效承压直径是否可替代图中 P 也没有受控成品图证明。因此叶端锚是实际缺口。只给一个**原创裸环几何示例**：叶 Ø6 光滑销、D≥15 mm；二级 Ø7 光滑销、D≥17.5 mm，均覆盖旧最大索径下的 5d。加标准环套后，承压点至套远端至少为 22.112 / 28.676 mm，尚不计尾长。它不是新商品型号、推荐磨损工况、端环强度证明或已设计锚座。正式方案需用受验证护环/端眼，或对实际光滑销端环做保持与往复试验；不能默认将小裸环长期铰动视为合格。

## 制作前的具体输入与检查

下一机构包需要先确定三只差动动轮与各转向轮的数量、轴线、包角、中心轨迹、护罩和端环摆角，保持索路共面并避免侧缘摩擦。任何索向改变都要回算实际张力和速度；返程回位和防松弛是独立设计任务。端孔、绳夹或弹簧不得仅因本包已有候选而随意添加。

样件验证应记录本批线径、槽根径、装配偏摆、环套尺寸、模腔/工具和操作者；在独立受保护的试验夹具上先测端部拉脱/破断与滑移，再测完整路径的迟滞、摩擦、松弛和目标循环谱。载荷等级、试样数、允许损伤/伸长与更换判据需事先定义。本文没有下达按索破断力某一固定百分比做现场预拉的操作指令。进入抓取验证前仍须独立托住工件；候选目录参数不等于抓 2 kg 已通过。

`bom.csv` 中滑轮/端套数量按“每个轮/每个端头”给出，系统总数、截索长度、压接耗损和总质量 TBD。只有线质量可按实际长度累加；不以包围盒体积推尼龙轮、轴承、环套的重量。

## 复现与审查

在仓库根目录运行：

```sh
python3 engineering/electronics/r5-cable-hardware01/calculate.py
python3 engineering/electronics/r5-cable-hardware01/verify.py
```

脚本仅写本包 JSON/CSV/SVG；不联网、不改旧包。14 项算术和边界断言用于防止单位/倍率/条件表错误，不是机械试验。原始来源与冲突见 [r5-cable-hardware01.json](../sources/r5-cable-hardware01.json)。本包原创分析、数据组织和图采用 CC-BY-NC-4.0；原厂资料版权归原权利人。

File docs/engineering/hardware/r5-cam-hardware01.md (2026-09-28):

# R5-CAM-HARDWARE01：单瓣凸轮随动器与分体根铰支承候选

状态：**元件级条件筛选完成；单瓣装配、四瓣包装、制造公差与夹持额定未放行。** 本研究保持 STAGE01 的 a=8 mm、相位 −45°、R=31…91 mm、q=0…90°，不修改冻结槽线和 FORM02。唯一主随动器候选为 **IKO CFS4**；根铰条件候选为每瓣 **2×SKF 607/8-2Z**。自制摇臂、短轴颈、止动和槽板仍需由实际载体结构定尺寸。

原 Ø6 滚轮/6.3 mm 槽仅为几何占位。真实 Ø8 件需要另建槽宽；本研究用 **8.05 mm** 作公差讨论，不把它回写为已批准结构。四瓣各一只 CFS4 加八只 SKF 轴承的目录质量小计为 **73.6 g**，不含随附螺母、轴、摇臂、壳体、盖板和其他紧固件。

## 原厂件与装配基准

| 项目 | IKO CFS4 主候选 | SKF 607/8-2Z 根铰候选 |
|---|---|---|
| 形式 | 碳钢、保持架、圆柱外圈、普通级；不是 F/V/W 变型 | 双防尘盖深沟球轴承；不是 619/8-2Z |
| 主尺寸 | 外径 8、外圈宽 5、螺杆 Ø4 h6、M4×0.7 | 内径 8、外径 19、宽 6 mm |
| 动/静额定 C / C₀ | 1120 / 1120 N | 2340 / 950 N |
| 另行约束 | 最大容许静载 919 N；40 HRC **平面钢轨**容量 799 N | 轴肩直径 10…11、壳肩开口 ≤17、圆角 ≤0.3 mm |
| 目录质量 | 本体参考 4 g；螺母另计 | 单只参考 7.2 g |
| 转速 | 保持架/脂润滑 d₁n 推荐 8400、最大 84000，即 Ø4 对应 2100/21000 rpm | 参考 85000、极限 43000 rpm；并非本应用振摆寿命证明 |

数据来自 [IKO 当前原厂目录](https://ikont.com/api/directus-asset/e5d07c75-b960-4d38-99c0-e7a95f037172?modified_on=1775854492829)、可复核的 [IKO 中文原厂目录 PDF 12–17 页](https://ikowb01.ikont.co.jp/technicalservice/download/pdf_catalog/1569CN.pdf)，以及 [SKF 原厂目录印刷 262–263 页](https://cdn.skfmediahub.skf.com/api/public/0901d196802809de/pdf_preview_medium/0901d196802809de_pdf_preview_medium.pdf)。来源、页码和本地参考文件哈希见 [来源登记](../sources/r5-cam-hardware01.json)。同样 8×19×6 的 619/8-2Z 静额定仅 465 N，不能混用。

以 CFS4 固定肩面为 u=0，+u 指向螺纹端：前总成 −7…0；**滚动外圈 −6…−1，中心 −3.5**；光杆 0…4；螺纹 4…8 mm。随附 M4 螺母厚 3.2、对边 7、对角参考 8.1 mm。候选 4 mm 摇臂座使螺母占 4…7.2，名义露头 0.8 mm。孔为 4 H6（4.000…4.008），支承肩面直径至少 7.7 mm；实际倒角、螺纹退刀、拧紧工具和防松尚未闭合。**0.777 N·m 是目录拧紧上限，不是已经确定的安装扭矩**；固定头部、转动螺母，不能把头部内六角当成拧入板内的安装方式。该尺寸不带补脂孔，内部已封脂，外部滚道仍需润滑方案。

原创轴向装配基准

[机械接口 JSON](../../../engineering/electronics/r5-cam-hardware01/mechanical-interface.json) 将目录尺寸、原创装配假设及未知项分开。该图是尺寸关系草图，不是原厂 BREP 或完整公差实体。4 mm 槽板居中于外圈时，名义两侧各留 0.5 mm；考虑外圈宽度下限 4.88 后仅各 0.44 mm，仍未扣安装偏斜。

## 单片受力，不能用路径总推力除以四

每片在径向–Z 平面建模，q 正向闭合。相对铰心的材料质心为 (x,z)，铰心随 R 平移。令

\[
A_c=-x\sin q-z\cos q,\quad B_c=x\cos q-z\sin q,
\]
\[
a_r=\ddot R+A_c\ddot q-B_c\dot q^2,\qquad a_z=B_c\ddot q+A_c\dot q^2.
\]

FORM02 已建材料的单上/下片质量为 71.4579/46.4958 g；绕根铰的惯量为 0.000535407/0.000147936 kg·m²。它们**不含 LED、PCB、线、滚轮、摇臂和紧固件**。保留移动铰耦合后，所需闭合方向力矩为

\[
\tau=J_H\ddot q+mA_c\ddot R+mgB_c.
\]

槽中心线 \(c=[R+a\cos(q-\pi/4),\ 0.020+a\sin(q-\pi/4)]\)，取 \(n=(-c'_z,c'_r)/|c'|\)。滚轮有效力臂 \(h=a\cos(q-\pi/4)/|c'|\)，所以**有符号法向反力 F_c=τ/h**。负号表示换到另一侧槽壁。本模型的 h 最小为 4.712714 mm，q90 的直槽段 h=5.656854 mm。

独立重构每支路径广义力 \(F_s=-ma_r+F_c n_r\)，两上两下之和分别恢复 STAGE01 的 69.283792 N 和 39.757852 N；不是先把这两个数除四。全周期功–能残差 ≤3.74×10⁻⁸ J；从质心位置作独立二次有限差分，加速度最大误差 ≤0.0222 m/s²（25 μs 采样，包含分段 C² 接点），相对各自峰值 <0.05%。

| 1 s 空载往返时程 | 单上片最大 \|F_c\| | 单下片最大 \|F_c\| | 轴承内外圈相对转速上界 |
|---|---:|---:|---:|
| 五次径向输入 | 66.665 N | 18.220 N | 887.471 rpm |
| STAGE01 Bernstein9 输入 | 24.236 N | 7.194 N | 568.452 rpm |

单纯重力造成的最大上/下反力为 9.228/3.951 N；惯性项、总项峰值发生时刻不同，不能相加成新的“实测峰值”。以上是同步、无接物、无间隙冲击的已建材料模型；被动差动分支不同步时须重算。

每瓣空载载荷及相对转速

滚轮中心沿槽移动，轴钉随片转动，不能只算中心速度除半径。保守相对角速度为 \(|v_{track}|/r+|\dot q|\)。实际加载壁纯滚动计算也已输出；力换号时该旋转速度可能突变，实物需经历间隙跨越、滑移/碰撞。推荐转速满足不代表该换边冲击、振摆润滑或循环寿命已满足。

## 夹持静载比空载更关键

此处采用**显式算例**：四个均衡接触、2 kg 工件、重力载荷因子 2、假设 μ=0.4、局部接触 x=65 mm、发光接触面高于铰轴 6 mm，head 重力沿 −Z。每片 N=24.516625 N，设计向下切向力 Fₜ=9.80665 N。因子 2 是设计载荷，不表示静置工件实际重量变为 4 kg。

\[
\tau_{cam}=0.065N-0.006F_t-mgz_{COM,hinge},\quad F_c=\tau_{cam}/(0.008/\sqrt2).
\]

只计物体法向为 **1.593581 N·m、281.708 N**；加入片重但不计切向力为上/下 **281.621/281.654 N**；再加入上述切向力后为 **271.219/271.252 N**。这些分量没有被隐藏进“空载很小”的结论。q90 最大闭角止挡通常抵抗继续闭合，**不能替代抵抗展开力矩的导槽**；可解锁止回/双向锁止目前均未设计。

以约 281.7 N 的法向单项检查，CFS4 的 C₀/载荷约 3.98、结构上限/载荷约 3.26、原厂平轨容量/载荷约 2.84。本研究参考 IKO 高精度情景而选择静态筛选目标 C₀/F≥3；它不是用户给定或整机强制要求。工件重力载荷因子2用于构造需求载荷，C₀/F则是额定与该需求的比值，两者分别报告，不将它们混作同一个安全系数。这仅是一个筛选目标，结构最大载荷与轨面接触还要分别检查。原占位尺寸对应 CFS3 的 C₀=611 N，约 2.17，故不保留为主选。

[静载扫参 CSV](../../../engineering/electronics/r5-cam-hardware01/static-grip-scenarios.csv) 给出 μ=0.2/0.3/0.4/0.6、x=35/65/95 mm 及法向分量/含切向力两种情况。μ 未测，不可把 0.4 当材料属性；x95 也不是已证明位于每块下片可用面内。**μ0.4、x95 的下片约401.27 N，C₀/F≈2.79，已不满足所选静态目标；μ0.2、x95约812.998 N，更超过799 N平轨目录值。** 因此此选型不是整个50–120 mm物体范围或任意接触位置的上界。更大摇臂/限制接触区/提高实测摩擦都需要重新验证，而不能只限电机电流后宣称额定2kg。

## 弯槽、材料和游隙

中心线数值最小曲率半径为 5.453590 mm。Ø8 的半径 4 小于该值；8.05 mm 槽的内侧偏置半径最小约 **1.428590 mm**，局部偏置正规性余量 **0.261954**。这只是稠密数值检查，不是全域区间证明，也不是加工刀具可达性验证。

799 N 是 40 HRC 平面钢轨条件；**不适用于打印塑料、未热处理铝或直接套到小曲率凸壁**。本研究另用同材钢 E=210 GPa、ν=0.3、有效线接触长度 4 mm 的 Hertz 理想模型：

\[
R_e=r(1\pm r\kappa),\quad p_0=\sqrt{|F_c|E^*/(\pi L R_e)}.
\]

取两壁更不利的一侧，最小等效半径仅 1.066153 mm。按平轨目录值作等应力比例**代理** \(799(4/5)(R_e/r)\)，全程最小为170.371 N；它不是原厂弯轨额定。同步五次/优化时程上片的“同位置载荷/代理值”峰值分别0.15474/0.13053，乘1.5动态因子后0.23211/0.19579；不把只发生在小曲率折叠段的170N与发生在直槽q90段的282N错误相比较。五次/优化时程的上片理想峰值 Hertz 压力约356.2/214.6 MPa；实际边缘接触、倒角、粗糙度、偏斜和冲击均可提高应力。4 mm 接触宽度折算本身也是工程代理，不能据此出硬度/热处理制造放行。

普通级外径是**平均直径**7.992…8.000，径向跳动上限15 μm，内部径向间隙3…17 μm。8.05 mm槽按名义外径的外部单边游隙25 μm，最不利 h 处线性化角游隙约±0.304°；只把平均外径下限代入则±0.353°。均未包含全部公差，不能当最终回差保证。载体并行研究仍保留8.3 mm槽：它的内偏置最小半径1.303590 mm、局部正规性余量0.239033，单边间隙仍是0.15 mm，因此线性化角游隙仍约±1.824°。与旧6/6.3数值相同是间隙相同，并非允许继续用旧滚轮实体；8.05讨论值不能代替载体实际8.3。

未找到 Ø8 CFS 的原厂偏心/预压变型。真实偏心 CFES 家族最小 Ø16，半径8超过现槽中心曲率半径，不能直接替换。把一只滚轮压紧两壁也不是可用的无间隙滚动：运动时两接触点要求相反自转。可调整双独立滚轮、轨板调整或单向回位预载属于后续结构研究，本次没有虚构现成型号。

## 短轴支承和轴向包装

不以贯穿轴穿过 FORM02 原有实体根部；由连接托架和两侧分离短轴颈支承。607/8-2Z 的精确安装行已从 SKF 相邻目录页逐项对应；端盖只压适当外圈肩，不能压防尘盖。拟定轴承中心 y=±16 mm、跨度32，轴承宽区 y=±[13,19]，壳外径22是候选壁厚1.5，外端盖外径20、厚1仍待强度计算。

真实 CFS4 安装肩若在 y28.5、螺杆朝内：滚动面 y29.5…34.5，中心y32；端部到y20.5，距盖最外面y20只有0.5名义间隙。4mm槽板处在y30…34，可能决定整头紧凑性；四瓣手性、邻片碰撞由载体研究单独校核。不能只用滚轮Ø8球形包络代替这套轴向长度。

在上述 μ0.4/x65 静载算例，跨度32、滚轮y32的近/远轴承合力为上 **401.779/141.413 N**、下 **401.923/141.279 N**。保留片质心横向偏置，力与力矩残差 <2×10⁻¹⁵ N·m。近轴承 C₀比仅约2.364；若该根支承也要求静态系数3，则当前包装不满足，需减悬伸/加跨距/改变支承，而不能称通过。[反力扫参](../../../engineering/electronics/r5-cam-hardware01/split-root-reaction-sensitivity.csv) 同时保留30和33mm跨距例子。

约1.534 N·m的夹持矩必须通过真实摇臂→短轴/托架→灯片传递；轴承不会提供绕自身轴线的正传扭约束。Ø8短轴与3mm横销目前不是已选制造件：材料、孔边距、双剪/弯曲、疲劳、配合、防松及装入顺序均未闭合。反力表另列灯片质心横向镜像、滚轮仍在+Y的结果，适配内部全同手性研究；变化小于0.04 N，但最终载体自重和传扭实体仍须加入。

## 交付与复现

[BOM](../../../engineering/electronics/r5-cam-hardware01/bom.csv) 区分目录件与必须定制的未知接口；价格、库存及交期未核验。原厂PDF/图片只缓存于工作区，公开目录保留原创图、数据及来源，不重新分发厂商媒体。

在仓库根目录运行（Python需numpy、scipy、matplotlib）：

```sh
python engineering/electronics/r5-cam-hardware01/build_interfaces.py
python engineering/electronics/r5-cam-hardware01/calculate.py
python engineering/electronics/r5-cam-hardware01/draw.py
python engineering/electronics/r5-cam-hardware01/verify.py
```

`build_interfaces.py` 记录本地已取原厂参考文件的哈希；缓存不在公开库时，它保留已登记来源哈希，不联网补取或伪造新核验。输入哈希、分量载荷、速度与校核见 [budget.json](../../../engineering/electronics/r5-cam-hardware01/budget.json) 和 [verification.json](../../../engineering/electronics/r5-cam-hardware01/verification.json)。零数值审计错误不能替代实际装配、轨道寿命、碰撞或夹物试验。

SPDX-License-Identifier: CC-BY-NC-4.0。原创研究，非金属加工放行文件。

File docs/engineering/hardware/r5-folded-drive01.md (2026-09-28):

# R5-FOLDED-DRIVE01：单中央丝杆驱动的并列同步带折返

**结论：一套有明确目录零件的条件布局可继续；原轴直接安装带轮不可用，整套传动仍不能制造放行。** 采用两根独立支承小轴、两只现成 Ø6 Fairloc 带轮和两只异径联轴器，把皮带径向力交给新支承。对于旧 R5-LINK01 的 40 mm 滑块／R5-MOTION02 的 3200 rpm，名义轴向链从 243.8 缩为 **193.5 mm**，只减少50.3 mm；裸件名义宽度增至78.5 mm。支架、工具、线缆和整头空间均未闭合。

本研究只消费冻结的旧 LINK01/MOTION02 与 SLIDER-HARDWARE01。Ø112 mm 球的287.171 N、理想输入0.114262 N·m只是一个条件接触点，不能当盒体／瓶罐50–120 mm的全范围上限。本次没有采用或证明适配正在研究的径向机构，没有修改全头CAD、采购或联系厂家。

原创折返参考布局

## 唯一主候选与被排除的直接安装

| 件 | 确切目录身份 | 数量及接口 |
|---|---|---|
| 同步带 | **Gates 180-3MGT3-6 / 9400-53250** | 1；3 mm节距、60齿、180 mm节线长、6 mm宽。SDP目录构成码 `A36R53M060060` 是同规格GT3供货身份的另一个目录入口，不能不核对送货身份就自动替换。 |
| 带轮 | **SDP/SI A 6D53M030DF0906** | 2；30T、Ø6 `+0.025/0`孔、M3 Fairloc、总长20.6±0.4、毂突出7.5、法兰Ø31.8±0.4 mm。适配GT2/GT3/FHT3且带宽≤9 mm。 |
| 电机侧联轴器 | **NBK MST-16C-5-6** | 1；Ø5电机→Ø6小轴。 |
| 丝杆侧联轴器 | **NBK MST-16C-4.5-6** | 1；Ø4.5丝杆→Ø6小轴。 |
| 独立小轴轴承 | **SKF 626-2Z** | 4；每轴2只，6×19×6 mm。 |
| 小轴、桥架、张紧和保持件 | 原创需求图，**无现成SKU** | 2根小轴；轴承桥、轴向保持及整电机模块调整结构待详细设计。不是“购买带轮后即可装机”。 |

带/带轮依据：[Gates 2024目录](https://www.gates.com/content/dam/gates/home/knowledge-center/resource-library/catalogs/industrial-power-transmission-catalogue-en.pdf)、[SDP D815 2-162/2-170](https://sdp-si.com/D815/D815-Metric-Section2-Belt-and-Chain-Drives.pdf)。NBK两个孔径组合确实列在[原厂MST-16C表](https://www.nbk1560.com/en/products/coupling/couplicon/slit_type/MST-C/MST-16C/)；不是把自制钻孔写成stock型号。目录存在不等于现时有货，未记录价格。

NBK两件都是Ø16×23 mm，每侧推荐插入6.5 mm、M2.5螺钉1 N·m，目录额定0.5 N·m／39000 rpm；需要按[参考回转径Ø17.6](https://www.nbk1560.com/images/en-US/product/contents/yougo_kaitenchokkei_coupling_NBK/yougo_kaitenchokkei_coupling_NBK_1.pdf)留位。0.5 N·m额定与本研究0.28 N·m设计筛查可比较，但不能替代选定轴公差下的夹紧滑移试验。[型号尺寸表](https://www.nbk1560.com/images/en/product/slit_type/MST-C/MST-C_1.pdf)及[安装说明](https://www.nbk1560.com/en-US/resources/coupling/article/couplicon-maintenance/)是插入和误差配合依据。

**直接安装反例**：该现成带轮孔径6，既不适配电机5，也不适配丝杆4.5。带轮20.6总长亦不能简单套进电机13±0.3或丝杆7.5的轴段。即使另做异径薄轮，仍是新的定制零件，必须重新核对夹持长度、法兰与锁母以及悬臂载荷。本次不把它列作第二套已选候选。

## 预紧必须计入轴承载荷

等径30T带轮，节径 `Dp = 30×3/π = 28.647890 mm`，中心距 `C=(180−90)/2=45 mm`，每轮包角180°／15齿啮合；3200 rpm时带速4.8 m/s。名义调整研究区42–48 mm尚不是已验证的装带、张紧行程。

以0.140 N·m为**假定静矩预算**，取显式服务系数2，设计转矩0.28 N·m。Gates的3MGT／6 mm每跨最低预紧2.4 lbf=10.6757 N；按其 `T₀=max(Tmin,1.21Q/Dp+M S²)`、M=0.078计算，S用千ft/min并完成力单位转换，得到12.1361 N/跨。这里仅为计算采用 `[12.1361,13.3497] N/跨` 的+10%敏感区间，**不是发布的装配张紧值**。Gates通用表14 lbf/跨若直接使用，会带来124.55 N静态径向合力；不能忽略它。[Gates设计手册，PDF67](https://www.gates.com/content/dam/documents-library/catalogs/light-power-and-precision-manual.pdf)

令两跨弹性对称、准静态分摊差张力：

```text
ΔT = τ / (Dp/2)
Ttight = T₀ + Tc + ΔT/2
Tslack = T₀ + Tc − ΔT/2
Fradial = Ttight + Tslack = 2(T₀+Tc)
Tc = (mbelt / Lbelt) v²
```

实际0.140 N·m的差张力9.77384 N；设计0.28时19.54769 N。采用目录带质量3 g的动态示例，Tc=0.384 N/跨，预紧区间上端对应**27.46746 N径向力**，两跨保持正张力。这不包含跑偏、齿啮合冲击、张紧误差和弹性波动；3 g也不是称重公差保证。

目录30T／3200 rpm／6 mm运行转矩1.96 N·m，180 mm长度系数0.85后为1.666 N·m，超过0.28的筛查要求；这是运行传动能力比较，不能推出零速握持、反复换向定位或疲劳寿命已合格。[同一Gates手册，PDF21](https://www.gates.com/content/dam/documents-library/catalogs/light-power-and-precision-manual.pdf)

## 载荷路径与真实轴端

独立小轴后轴承中心Z3、前轴承中心Z35，带载荷规划中心Z22.55 mm。径向力27.46746 N时，静态梁反力后10.68656／前16.78090 N。即把载荷位置放宽到整个法兰段Z16–29.1，单轴承最大也为22.40315 N。SKF表列C2340、C₀950 N、极限40000 rpm，只说明目录量级足够进入装配设计；没有替代配合、温升和寿命计算。[SKF目录PDF262–263](https://cdn.skfmediahub.skf.com/api/public/0901d196802809de/pdf_preview_medium/0901d196802809de_pdf_preview_medium.pdf)

对Ø6、32 mm简支跨度、E=210 GPa的纯梁筛查，弯矩0.20892 N·m、弯曲应力9.852 MPa、载荷点挠度0.001269 mm。它不含肩部应力集中、配合、扭转疲劳和桥架柔度，不能当小轴强度放行。后端选Ø9肩符合SKF给的8.4–9.4肩径范围／圆角≤0.3；轴承轴颈配合、轴向保持槽与材料均未指定。前轴承外圈应有定义清楚的轴向随动，不能随意施加预紧。

电机[3274原厂](https://www.faulhaber.com/fileadmin/Import/Media/EN_3274_BP4_DFF.pdf)的50 N径向数值只对应3000 rpm及距法兰5 mm。假定直接带轮距法兰1 mm、毂7.5、余下部分中点6.55，则带力臂15.05 mm；把27.46746 N按等弯矩映射到5 mm得82.6771 N。**此映射只是保守对比，不是厂家给出的承载缩放定律**；更不能把3000 rpm指标自动延到3200。主候选用联轴器只传递扭矩，将皮带径向反力导向独立桥架；偏心联轴器残余反力仍需校核。

丝杆的287 N条件轴力仍经MSU-6C角接触对进入机架，不经电机或新小轴支承。主方案理想情况下不再给MSU增加皮带径向载荷；如果取消丝杆侧小轴、把带轮改到丝杆上，就必须另算MSU/短细轴/锁母悬臂，不属于本方案。

原创小轴及锁母接口需求图

原厂[KSS A219](https://kssballscrew.com/us/pdf/catalog/A219.pdf)固定端总30 mm，包括Ø4.5 h6×7.5、M6×0.75×7和推导15.5 mm轴承段。新下载的[KSS MSU6C IGES](https://www.kss-superdrive.co.jp/jp/cad/3d/MSU6C.zip)有130个面、没有封闭实体；参考轴承肩native Z−14.5与锁母前面+7.5相差22 mm，与[MSU目录参考尺寸(L2)=22](https://kssballscrew.com/us/pdf/catalog/E107-E108.pdf)一致。若肩正确贴合，尖到锁母面名义8 mm；联轴器插入6.5后有**1.5 mm名义端面间隙**。不可把这写成实装公差保证或工具进入已经通过。

原厂IGES两轴承参考包络合计11.5 mm，与裸MTA06-15HP5DF目录单只5.5 mm×2不同。保留这个0.5 mm来源差异，不用表面CAD推导真实轴承宽、压紧或预紧。[提取审计](../../../engineering/electronics/r5-folded-drive01/msu-reference-audit.json)给出原文件hash、面分组及假设；厂家文件只存work，没有随项目再分发。

## 折返尺寸、质量与惯量代价

本地坐标与head无绑定：丝杆轴X0、电机轴X45，两者Y0、平行Z。小轴后肩Z−3–0，轴承Z0–6／32–38，带轮Z8.5–29.1，联轴器Z42–65；电机/丝杆尖Z58.5，电机法兰Z71.5，3274+IE3组合后端Z162.3。130 mm请求丝杆末端Z188.5。取未设计桥架后边界Z−5，只得到下述**参考链**：

| 量 | 数值与范围 |
|---|---|
| 名义裸件参考包络 | 78.5×32×193.5 mm；法兰最大已知尺寸会使宽/高至少变成78.6/32.2，仍未形成全公差包络。 |
| 均匀加3 mm的展示盒 | 84.5×38×199.5 mm；不是罩壳结构，不包含真实桥架、螺母耳座、导轨安装偏置、工具或线缆。 |
| 与原直列比较 | 130 mm请求轴243.8→193.5 mm，省50.3；原170 mm stock轴283.8→233.5 mm，同样只省50.3。 |
| 目录/典型质量已知小计 | 534.4 g：motor、IE3典型、MSU两支承、两导块/115 mm轨、4轴承、带。 |
| 混合参考小计 | 800.876 g：再加联轴器最大孔参考、两个带轮/小轴名义几何代理和丝杆/螺母代理。**不是实际组件重量、保证上界或整头质量。** |

新小轴/带轮代理采用明确的实心环/圆柱计算；全部单项在[budget.json](../../../engineering/electronics/r5-folded-drive01/budget.json)。全头、支架、保持件、紧固件、护罩等未分配，`whole_head_mass_kg=null`。3274+IE3长度90.8±0.6来自[IE3组合图](https://www.faulhaber.com/fileadmin/Import/Media/EN_IE3-1024L_DFF.pdf)，没有用电机裸长代替。

将两个带轮与小轴代理、两联轴器最大孔参考惯量及带的平动等效惯量相加，得到 `Jadd=9.67720×10⁻⁶ kg·m²`。这个混合值既非实际值，也非保证上界；其量级约为电机+编码器4.808×10⁻⁶的2倍。对冻结七段时序CSV逐点重算 `τnew=τold+Jadd αmotor`：

| −Z重力，旧已建指体、单1秒空载往返 | 未加折返J，CSV回读 | 混合J示例 |
|---|---:|---:|
| 峰转矩，含目录电机摩擦 | 0.025403 N·m | **0.047022 N·m** |
| 单周期RMS转矩，同上 | 0.012265 N·m | **0.027339 N·m** |
| 理想负机械功积分 | 0.717613 J | **1.803718 J** |
| 新增峰动能 | 0 | 0.543346 J |

0.5 ms CSV再积分与原MOTION02高密度结果有微小数值差异，未冒充原始积分精度。表中仍缺真实丝杆、滑座、连杆、带/轴承损失与实际接触动力；负机械功也不是母线必然收到的电能。1:1不改善保持机械优势，0.114262/0.140对应的总传力比例仍至少约0.8162，额外传动损失只会吃掉余量；0.140本身不是装壳持续保证。实际回生/发热必须重新进入SERVO预算。

## 如何使用这份结果

可用的是一套真实目录件身份、可复算载荷及原创接口需求图；可据此决定是否值得为50 mm长度收益承担宽度、惯量、零件和装配代价。**不能将现图下发加工或把它自动迁移到新径向机构。** 首要未闭合项是精确6 mm/M3 Fairloc的夹紧/滑移数据、小轴定位与浮动配合、桥架与调整机构、锁母/联轴器公差及工具路径。张紧时应移动电机及其整套支承，不横拉联轴器强行吸收中心距变化；装带不应撬越法兰。MSU成套预调支承不拆解。

B型130 mm丝杆仍是 `SG0802.5-080R130C5B1X` 配置请求，不是厂家确认SKU；3200 rpm也没有消除KSS对循环器加速度的限制。失电保持、机械限位、夹力控制和新物体适配均未被一条同步带解决。

复算（从仓库根目录，环境须有numpy/matplotlib；原厂IGES额外读取须cadquery/OCP）：

```sh
python engineering/electronics/r5-folded-drive01/calculate.py
python engineering/electronics/r5-folded-drive01/make_bom.py
python engineering/electronics/r5-folded-drive01/draw.py
python engineering/electronics/r5-folded-drive01/verify.py
# 可选：另行取得上述官方ZIP解包，不自动下载、也不修改旧研究
python engineering/electronics/r5-folded-drive01/audit_msu_reference.py /path/to/MSU6C.igs
```

[BOM](../../../engineering/electronics/r5-folded-drive01/bom.csv) · [精确坐标](../../../engineering/electronics/r5-folded-drive01/layout-parameters.json) · [载荷CSV](../../../engineering/electronics/r5-folded-drive01/tension-and-bearing-loads.csv) · [惯量敏感性](../../../engineering/electronics/r5-folded-drive01/added-inertia-sensitivity.csv) · [一手来源与hash](../sources/r5-folded-drive01.json)。验证文件只证明本研究计算和来源关联自洽，不证明实机或制造合格。

SPDX-License-Identifier: CC-BY-NC-4.0。Required Notice: Odradek — Auromix contributors (https://github.com/Auromix/odradek)。第三方资料权利归原权利人。

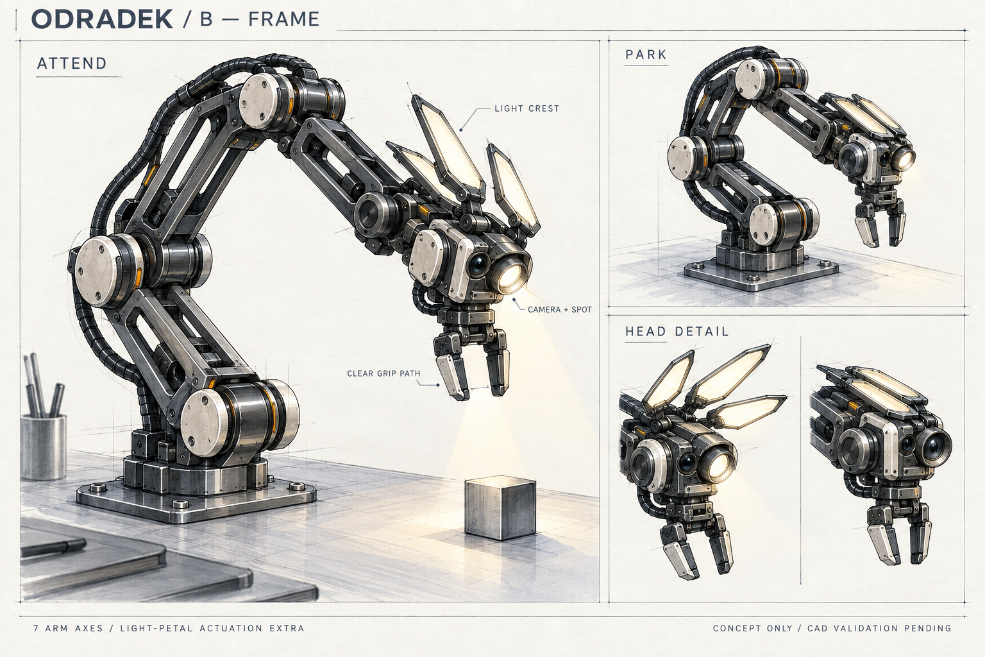
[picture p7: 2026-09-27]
docs/concepts/02-frame.png

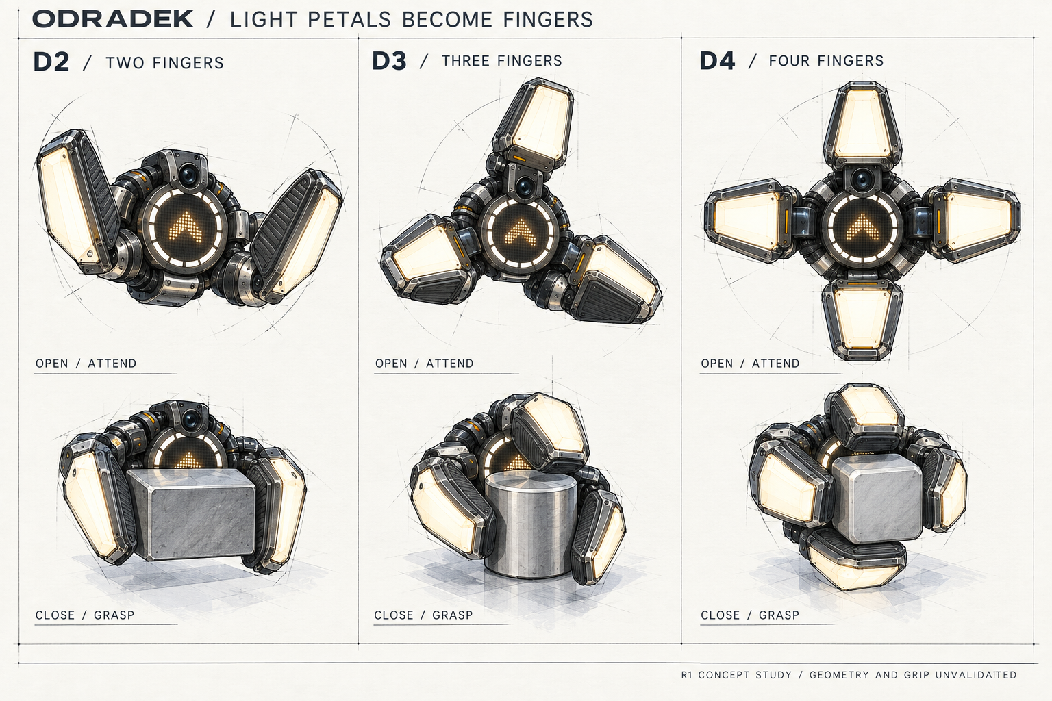
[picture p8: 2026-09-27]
docs/concepts/05-petal-gripper-options.png

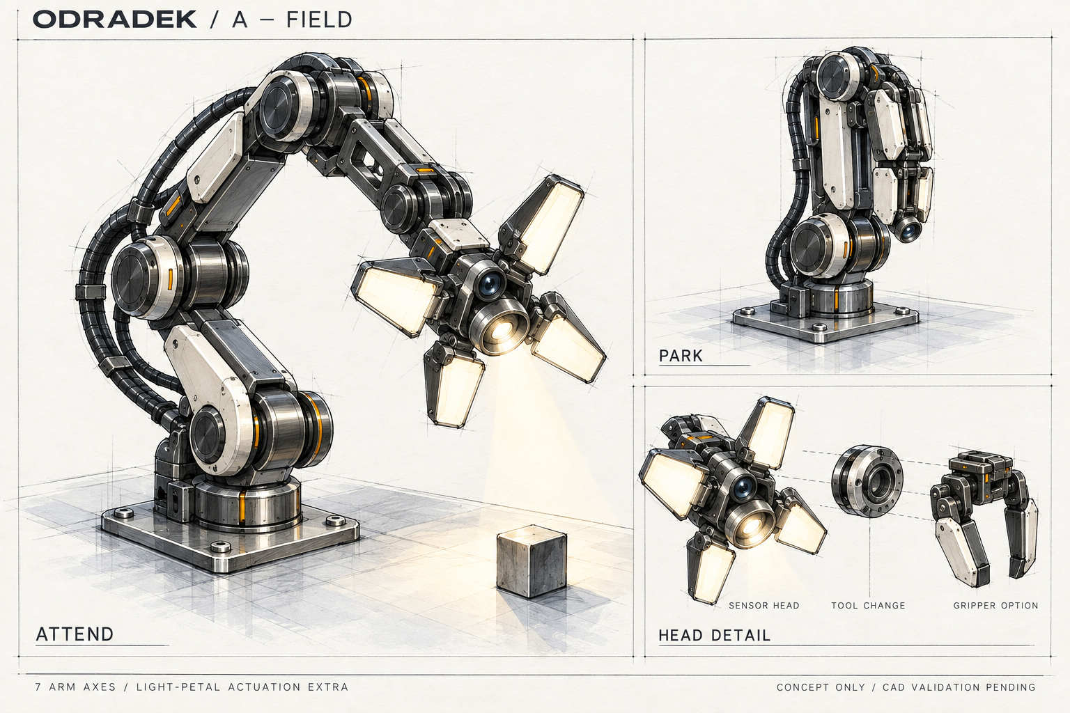
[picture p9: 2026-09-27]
docs/concepts/01-field.png

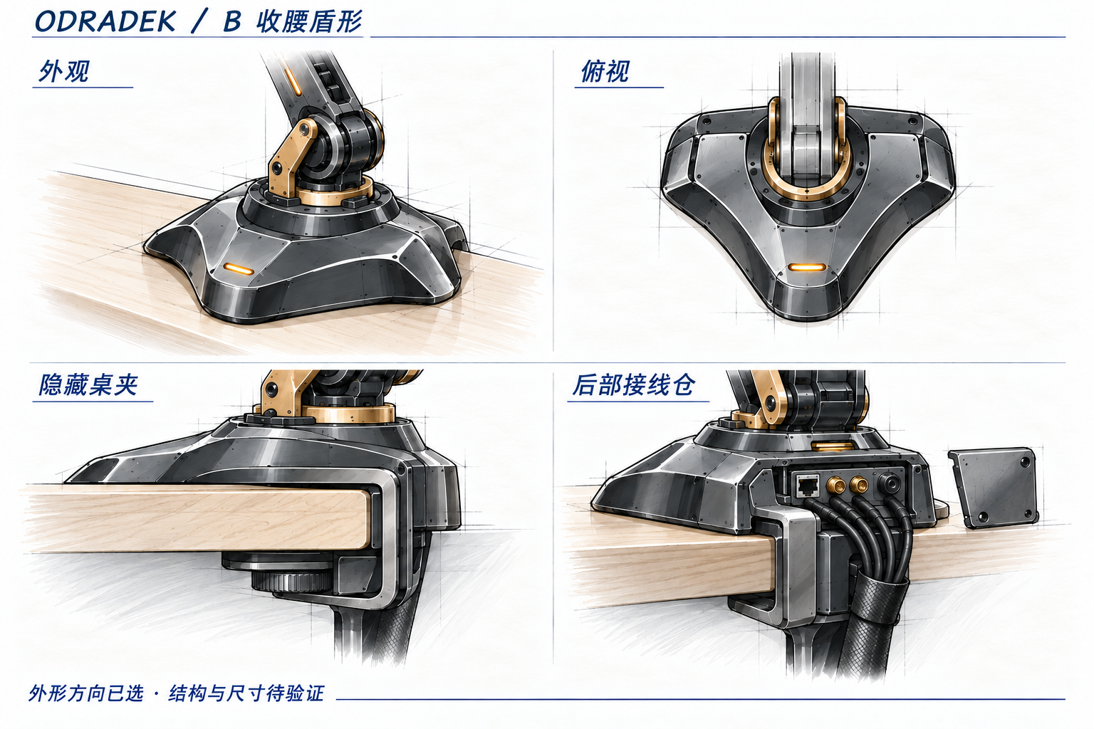
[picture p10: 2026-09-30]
docs/concepts/selected/base-b-shield.png

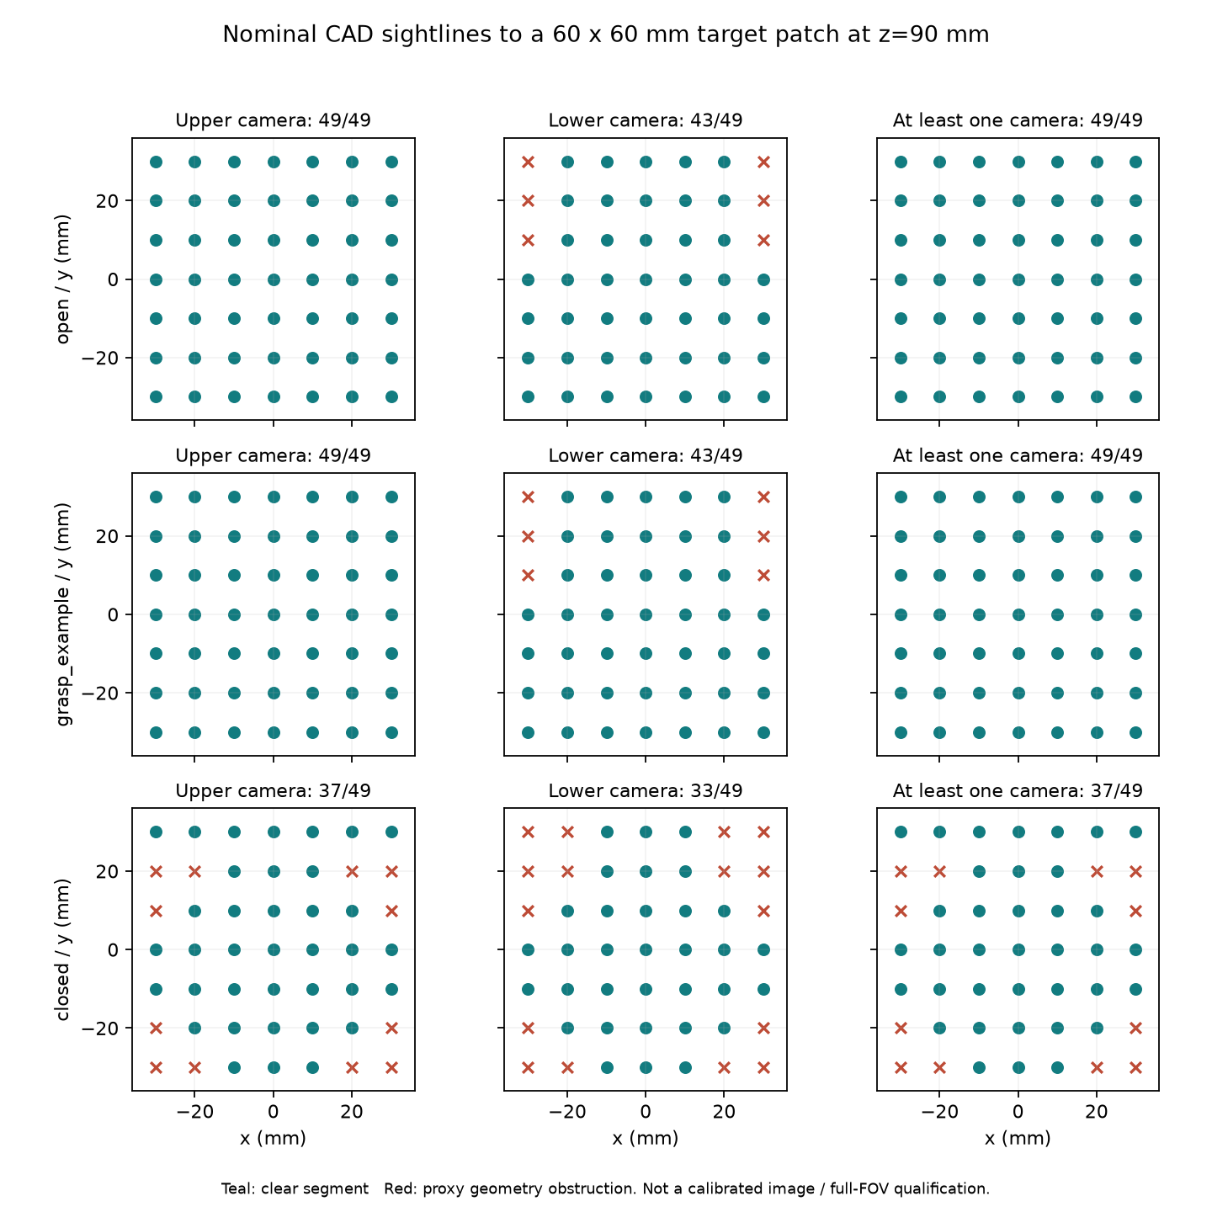
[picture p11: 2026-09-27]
docs/engineering/analysis/optical-sightline-screen.png

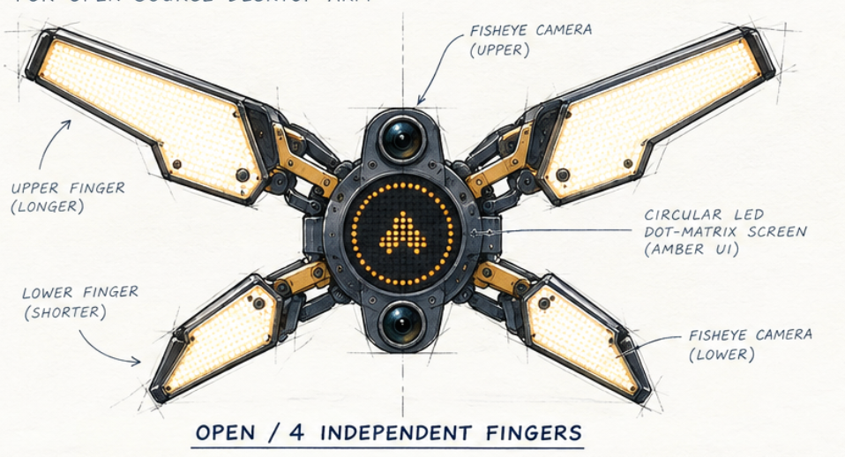
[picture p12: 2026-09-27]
docs/concepts/selected/head-open-reference.png

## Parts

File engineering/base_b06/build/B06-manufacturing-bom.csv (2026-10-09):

id | parent | quantity | unit | kind | specification | manufacturer_part | source | status | open_item
B06-101-LOAD-DECK | BASE | 1 | pcs | metal | CNC profile and drill/counterbore; weld assembly B06-W01 |  | load-frame/step/B06-101-LOAD-DECK.step | RFQ_CANDIDATE | 15 mm finished thickness; rear Y-59, table rear edge Y-45; corners deburr R0.5 | Datum A upper Z17; flatness0.15 after welding; no polymer carries arm preload
B06-102-REAR-WEB | BASE | 1 | pcs | metal | CNC plate profile/drill/tap; weld B06-W01 |  | load-frame/step/B06-102-REAR-WEB.step | RFQ_CANDIDATE | 8 mm thickness; top Z2; rear Y-59; Four z5 continuous fillets; leg5.0..5.5 clearance envelope at upper and lower plate joints | Front fillet nominal toe Y-46, maximum envelope Y-45.5; nominal desk edgeY-45; machine datums after weld/stress relief; no weld in desk pad seat
B06-103-LOWER-JAW | BASE | 1 | pcs | metal | CNC profile/drill/tap; weld B06-W01 |  | load-frame/step/B06-103-LOWER-JAW.step | RFQ_CANDIDATE | 14 mm finished thickness; two full steel threaded legs | M12 thrust screws turn from BELOW with AF6 key; no side knob hidden behind the box
B06-104-LOAD-FLANGE | BASE | 1 | pcs | metal | CNC turn/mill + drill/tap; clear anodize, mask datums |  | load-frame/step/B06-104-LOAD-FLANGE.step | RFQ_CANDIDATE | OD160/ID56 x12; upper mating datum Z58 flatness0.1; 8xM6 PCD120 phase22.5deg; interface-contract.json governs | Bottom open cable pocket X±17/Y28..83/Z46..48; breaks into central bore | No motor dependency: independent test adapter or arm module fits this same base interface
B06-105-POST-1 | BASE | 4 | pcs | metal | Turn + through drill/tap |  | load-frame/step/B06-105-POST-1.step;load-frame/step/B06-105-POST-2.step;load-frame/step/B06-105-POST-3.step;load-frame/step/B06-105-POST-4.step | RFQ_CANDIDATE | Four identical OD18 x29 spacers; ends parallel0.05 | M8 full through thread; top bolt engagement12.5, bottom13.5 mm; nominal tip gap3.0 mm
B06-106-DESK-PAD | BASE | 1 | pcs | soft | Cut 2 mm solid silicone, nominal60A; bond to deck |  | load-frame/step/B06-106-DESK-PAD.step | RFQ_CANDIDATE | Friction and desk-surface compression require bench test
B06-107-SPREADER--1 | BASE | 2 | pcs | metal | CNC flat plate; R2 edge breaks |  | load-frame/step/B06-107-SPREADER--1.step;load-frame/step/B06-107-SPREADER-1.step | RFQ_CANDIDATE | Foot bears directly on metal at (X±45,Y50); swivel foot retained by its supplied retaining spring | Place spreader during installation; pad must cover the entire contact footprint
B06-108-PRESS-PAD--1 | BASE | 2 | pcs | soft | Cut 2 mm solid silicone60A; bond to spreader |  | load-frame/step/B06-108-PRESS-PAD--1.step;load-frame/step/B06-108-PRESS-PAD-1.step | RFQ_CANDIDATE
HW-DIN6311--1 | BASE | 2 | pcs | hardware | Purchase Ganter DIN6311-25-S |  | load-frame/step/HW-DIN6311--1.step;load-frame/step/HW-DIN6311-1.step | RFQ_CANDIDATE | D25 x13; inverted flat face at spreader underside; snap ring supplied | Bore represented as conservative cylindrical clearance, supplier swivel seat omitted; sample fit required
HW-DIN6332--1 | BASE | 2 | pcs | hardware | Purchase Ganter DIN6332-M12-100-SK; AF6 |  | load-frame/step/HW-DIN6332--1.step;load-frame/step/HW-DIN6332-1.step | RFQ_CANDIDATE | Length100 includes thrust pin; thread portion conservatively90; thread class5.8 | Thrust seat approximation, not machining geometry; verify supplier seat/pin retention | Tighten from BELOW; do not print hardware
B06-201-HANGER--1 | BASE | 1 | pcs | metal | CNC profile from8 mm plate + drill/tap |  | load-frame/step/B06-201-HANGER--1.step | RFQ_CANDIDATE | Inward cantilever height20 mm; remove hanger independently of desk clamp; deburr R0.5
B06-201-HANGER-1 | BASE | 1 | pcs | metal | CNC profile from8 mm plate + drill/tap |  | load-frame/step/B06-201-HANGER-1.step | RFQ_CANDIDATE | Inward cantilever height20 mm; remove hanger independently of desk clamp; deburr R0.5
B06-202-TRAY | BASE | 1 | pcs | metal | CNC profile + drill/tap |  | load-frame/step/B06-202-TRAY.step | RFQ_CANDIDATE | Confirmed maximum box180x150x50 mm/3 kg; footprint X±90,Y120..270; slides +Y | 20 mm hook/loop straps secure vertically; front stop removable; ventilation not covered by this mechanical budget
B06-203-STOP-BACK | BASE | 1 | pcs | metal | Mill/drill |  | load-frame/step/B06-203-STOP-BACK.step | RFQ_CANDIDATE | Front stop removes before box slides toward +Y
B06-203-STOP-FRONT | BASE | 1 | pcs | metal | Mill/drill |  | load-frame/step/B06-203-STOP-FRONT.step | RFQ_CANDIDATE | Front stop removes before box slides toward +Y
B06-309-COAX-BRACKET | BASE | 1 | pcs | metal | CNC mill original RF bulkhead bracket |  | load-frame/step/B06-309-COAX-BRACKET.step | RFQ_CANDIDATE | Base2 mm at PCB top Z25.6; rear panel4.5 mm Y-19..-14.5; flange bearing face Y-16, internal fillet R1 | H5/H6 mounting centres X±10,Y-8; coax axes X±10,Z35; mounts independent of cosmetic rear lid | Fixed coax rear datum retained at Y-16, separate from RJ45/power PCB shift; bond to chassis via J6 lug
B06-307-LOWER-CARRIER | BASE | 1 | pcs | printed | FDM print; exported exact CAD geometry |  | load-frame/step/B06-307-LOWER-CARRIER.step | RFQ_CANDIDATE | Printed PCB/cover locating scaffold only; no arm or clamp load | Board bottom Z24; side-insert nuts Z19.2..21.6; rear screw axis Z32 | Retain 1mm nut-pocket floor and >=2.2mm roof; verify print fit coupon
HW-M8-TOP-1 | BASE | 4 | pcs | hardware | Purchase standard screw; strength class8.8 minimum for load-path screws |  | load-frame/step/HW-M8-TOP-1.step;load-frame/step/HW-M8-TOP-2.step;load-frame/step/HW-M8-TOP-3.step;load-frame/step/HW-M8-TOP-4.step | RFQ_CANDIDATE | M8x16; head envelope D13 x8; hex AF6 | Threads and chamfers omitted; dimensions are maximum planning envelopes, NOT hardware manufacturing STLs
HW-M8-BOTTOM-1 | BASE | 4 | pcs | hardware | Purchase standard screw; strength class8.8 minimum for load-path screws |  | load-frame/step/HW-M8-BOTTOM-1.step;load-frame/step/HW-M8-BOTTOM-2.step;load-frame/step/HW-M8-BOTTOM-3.step;load-frame/step/HW-M8-BOTTOM-4.step | RFQ_CANDIDATE | M8x20; head envelope D13 x8; hex AF6 | Threads and chamfers omitted; dimensions are maximum planning envelopes, NOT hardware manufacturing STLs
HW-HANGER-WASHER--1-1 | BASE | 4 | pcs | hardware | Purchase ISO7089 washer |  | load-frame/step/HW-HANGER-WASHER--1-1.step;load-frame/step/HW-HANGER-WASHER--1-2.step;load-frame/step/HW-HANGER-WASHER-1-1.step;load-frame/step/HW-HANGER-WASHER-1-2.step | RFQ_CANDIDATE
HW-HANGER-M6--1-1 | BASE | 4 | pcs | hardware | Purchase standard screw; strength class8.8 minimum for load-path screws |  | load-frame/step/HW-HANGER-M6--1-1.step;load-frame/step/HW-HANGER-M6--1-2.step;load-frame/step/HW-HANGER-M6-1-1.step;load-frame/step/HW-HANGER-M6-1-2.step | RFQ_CANDIDATE | M6x20; head envelope D10 x6; hex AF5 | Threads and chamfers omitted; dimensions are maximum planning envelopes, NOT hardware manufacturing STLs
HW-TRAY-M4-1 | BASE | 4 | pcs | hardware | Purchase standard screw; strength class8.8 minimum for load-path screws |  | load-frame/step/HW-TRAY-M4-1.step;load-frame/step/HW-TRAY-M4-2.step;load-frame/step/HW-TRAY-M4-3.step;load-frame/step/HW-TRAY-M4-4.step | RFQ_CANDIDATE | M4x10; head envelope D7.6 x2.2; hex AF2.5 | Threads and chamfers omitted; dimensions are maximum planning envelopes, NOT hardware manufacturing STLs
HW-STOP-M4-BACK--88 | BASE | 4 | pcs | hardware | Purchase standard screw; strength class8.8 minimum for load-path screws |  | load-frame/step/HW-STOP-M4-BACK--88.step;load-frame/step/HW-STOP-M4-BACK-88.step;load-frame/step/HW-STOP-M4-FRONT--88.step;load-frame/step/HW-STOP-M4-FRONT-88.step | RFQ_CANDIDATE | M4x20; head envelope D7.6 x2.2; hex AF2.5 | Threads and chamfers omitted; dimensions are maximum planning envelopes, NOT hardware manufacturing STLs
HW-COAX-TOP-WASHER--1 | BASE | 4 | pcs | hardware | Purchase ISO7089 washer |  | load-frame/step/HW-COAX-TOP-WASHER--1.step;load-frame/step/HW-COAX-BOTTOM-WASHER--1.step;load-frame/step/HW-COAX-TOP-WASHER-1.step;load-frame/step/HW-COAX-BOTTOM-WASHER-1.step | RFQ_CANDIDATE
HW-COAX-M3--1 | BASE | 2 | pcs | hardware | Purchase standard screw; strength class8.8 minimum for load-path screws |  | load-frame/step/HW-COAX-M3--1.step;load-frame/step/HW-COAX-M3-1.step | RFQ_CANDIDATE | M3x8; head envelope D5.7 x1.65; hex AF2 | Threads and chamfers omitted; dimensions are maximum planning envelopes, NOT hardware manufacturing STLs
HW-COAX-NUT--1 | BASE | 2 | pcs | hardware | Purchase DIN934 M3 nut; nominal unthreaded bore envelope |  | load-frame/step/HW-COAX-NUT--1.step;load-frame/step/HW-COAX-NUT-1.step | RFQ_CANDIDATE
B06-301-MAIN-SHIELD | BASE | 1 | pcs | printed | FDM; 0.4 nozzle target; final slicing/fit coupon required |  | exterior/print-parts/B06-301-MAIN-SHIELD.stl | RFQ_CANDIDATE | Printed locating/cosmetic component, no arm load
B06-306-LIGHT-LENS | BASE | 1 | pcs | printed | FDM; 0.4 nozzle target; final slicing/fit coupon required |  | exterior/print-parts/B06-306-LIGHT-LENS.stl | RFQ_CANDIDATE | Printed locating/cosmetic component, no arm load
B06-308-LENS-RETAINER | BASE | 1 | pcs | printed | FDM; 0.4 nozzle target; final slicing/fit coupon required |  | exterior/print-parts/B06-308-LENS-RETAINER.stl | RFQ_CANDIDATE | Printed locating/cosmetic component, no arm load
B06-304-REAR-LID | BASE | 1 | pcs | printed | FDM; 0.4 nozzle target; final slicing/fit coupon required |  | exterior/print-parts/B06-304-REAR-LID.stl | RFQ_CANDIDATE | Printed locating/cosmetic component, no arm load
HW-COVER-PCB-REAR-M3 | BASE | 10 | pcs | purchase | ISO7380-1 M3x10, AF2, head D5.7x1.65 |  |  | RFQ_CANDIDATE | Current model / confirmed box budget
HW-COVER-PCB-REAR-NUT | BASE | 10 | pcs | purchase | DIN934 M3 nut AF5.5 x2.4 |  |  | RFQ_CANDIDATE | Current model / confirmed box budget
HW-LIGHT-M2 | BASE | 2 | pcs | purchase | ISO4762 M2x8, AF1.5, head D3.8x2 |  |  | RFQ_CANDIDATE | Current model / confirmed box budget
HW-LIGHT-NUT | BASE | 2 | pcs | purchase | DIN934 M2 AF4 x1.6 |  |  | RFQ_CANDIDATE | Current model / confirmed box budget
SHELF-STRAP | BASE | 1 | pcs | purchase | 20mm hook/loop strap, minimum600mm; trim to box after installation |  |  | RFQ_CANDIDATE | Current model / confirmed box budget
PCB-B06-IO | BASE | 1 | pcs | assembly_parent | Native JLCEDA CONTROL-01 fabrication candidate; DRC0; local5V and STM32 PWM |  | ../electronics/base-io-b05/manufacturing/b06-io-control01/ | RFQ_CANDIDATE | Assembly parent; 26 physical components; previous13-part Gerber historical; do not buy both populated PCBA and separate components
PCB-B06-LIGHT | BASE | 1 | pcs | assembly_parent | 50x14; independent 5V PWM; 12 SMT parts; native BOM/pick-place |  | ../electronics/base-light-b06/manufacturing/ | RFQ_CANDIDATE | JST GH: 1=5V,2=PWM,3=GND; DO NOT CONNECT48V
PCB-B06-IO/C1 | PCB-B06-IO | 1 | pcs | component_child | 10uF | C5750X7S2A106K230KB | electronics/base-io-b05/manufacturing/b06-io-control01/B06-IO-CONTROL01-BOM.csv | NATIVE_BOM_VERIFIED | Supplier availability/lot and PCBA process must be confirmed; buy either populated parent or children
PCB-B06-IO/C2,C4 | PCB-B06-IO | 2 | pcs | component_child | 1uF | CC0805KKX7R9BB105 | electronics/base-io-b05/manufacturing/b06-io-control01/B06-IO-CONTROL01-BOM.csv | NATIVE_BOM_VERIFIED | Supplier availability/lot and PCBA process must be confirmed; buy either populated parent or children
PCB-B06-IO/C3,C7 | PCB-B06-IO | 2 | pcs | component_child | 100nF | CC0603KRX7R8BB104 | electronics/base-io-b05/manufacturing/b06-io-control01/B06-IO-CONTROL01-BOM.csv | NATIVE_BOM_VERIFIED | Supplier availability/lot and PCBA process must be confirmed; buy either populated parent or children
PCB-B06-IO/C5,C6 | PCB-B06-IO | 2 | pcs | component_child | 10uF | T491A106K016AT | electronics/base-io-b05/manufacturing/b06-io-control01/B06-IO-CONTROL01-BOM.csv | NATIVE_BOM_VERIFIED | Supplier availability/lot and PCBA process must be confirmed; buy either populated parent or children
PCB-B06-IO/D1 | PCB-B06-IO | 1 | pcs | component_child | S1B-13-F | S1B-13-F | electronics/base-io-b05/manufacturing/b06-io-control01/B06-IO-CONTROL01-BOM.csv | NATIVE_BOM_VERIFIED | Supplier availability/lot and PCBA process must be confirmed; buy either populated parent or children
PCB-B06-IO/F1 | PCB-B06-IO | 1 | pcs | component_child | 0451.500MRL | 0451.500MRL | electronics/base-io-b05/manufacturing/b06-io-control01/B06-IO-CONTROL01-BOM.csv | NATIVE_BOM_VERIFIED | Supplier availability/lot and PCBA process must be confirmed; buy either populated parent or children
PCB-B06-IO/J1 | PCB-B06-IO | 1 | pcs | component_child | SHIELDED_RJ45 | 615008160221 | electronics/base-io-b05/manufacturing/b06-io-control01/B06-IO-CONTROL01-BOM.csv | NATIVE_BOM_VERIFIED | Supplier availability/lot and PCBA process must be confirmed; buy either populated parent or children
PCB-B06-IO/J2 | PCB-B06-IO | 1 | pcs | component_child | SHIELDED_RJ45 | 615008160221 | electronics/base-io-b05/manufacturing/b06-io-control01/B06-IO-CONTROL01-BOM.csv | NATIVE_BOM_VERIFIED | Supplier availability/lot and PCBA process must be confirmed; buy either populated parent or children
PCB-B06-IO/J3 | PCB-B06-IO | 1 | pcs | component_child | 48V_EXTERNAL | 1720466 | electronics/base-io-b05/manufacturing/b06-io-control01/B06-IO-CONTROL01-BOM.csv | NATIVE_BOM_VERIFIED | Supplier availability/lot and PCBA process must be confirmed; buy either populated parent or children
PCB-B06-IO/J4 | PCB-B06-IO | 1 | pcs | component_child | ARM_48V | 74651173 | electronics/base-io-b05/manufacturing/b06-io-control01/B06-IO-CONTROL01-BOM.csv | NATIVE_BOM_VERIFIED | Supplier availability/lot and PCBA process must be confirmed; buy either populated parent or children
PCB-B06-IO/J5 | PCB-B06-IO | 1 | pcs | component_child | ARM_RETURN | 74651173 | electronics/base-io-b05/manufacturing/b06-io-control01/B06-IO-CONTROL01-BOM.csv | NATIVE_BOM_VERIFIED | Supplier availability/lot and PCBA process must be confirmed; buy either populated parent or children
PCB-B06-IO/J6 | PCB-B06-IO | 1 | pcs | component_child | CHASSIS_BOND | 74651173 | electronics/base-io-b05/manufacturing/b06-io-control01/B06-IO-CONTROL01-BOM.csv | NATIVE_BOM_VERIFIED | Supplier availability/lot and PCBA process must be confirmed; buy either populated parent or children
PCB-B06-IO/J7,J8 | PCB-B06-IO | 2 | pcs | component_child | BM03B-GHS-TBT(LF)(SN) | BM03B-GHS-TBT(LF)(SN) | electronics/base-io-b05/manufacturing/b06-io-control01/B06-IO-CONTROL01-BOM.csv | NATIVE_BOM_VERIFIED | Supplier availability/lot and PCBA process must be confirmed; buy either populated parent or children
PCB-B06-IO/J9 | PCB-B06-IO | 1 | pcs | component_child | BM05B-GHS-TBT(LF)(SN)(N) | BM05B-GHS-TBT(LF)(SN)(N) | electronics/base-io-b05/manufacturing/b06-io-control01/B06-IO-CONTROL01-BOM.csv | NATIVE_BOM_VERIFIED | Supplier availability/lot and PCBA process must be confirmed; buy either populated parent or children
PCB-B06-IO/R1 | PCB-B06-IO | 1 | pcs | component_child | 470Ω | RC0805FR-07470RL | electronics/base-io-b05/manufacturing/b06-io-control01/B06-IO-CONTROL01-BOM.csv | NATIVE_BOM_VERIFIED | Supplier availability/lot and PCBA process must be confirmed; buy either populated parent or children
PCB-B06-IO/R2,R4,R5 | PCB-B06-IO | 3 | pcs | component_child | 10kΩ | RC0603FR-0710KL | electronics/base-io-b05/manufacturing/b06-io-control01/B06-IO-CONTROL01-BOM.csv | NATIVE_BOM_VERIFIED | Supplier availability/lot and PCBA process must be confirmed; buy either populated parent or children
PCB-B06-IO/R3 | PCB-B06-IO | 1 | pcs | component_child | 1kΩ | RC0603FR-071KL | electronics/base-io-b05/manufacturing/b06-io-control01/B06-IO-CONTROL01-BOM.csv | NATIVE_BOM_VERIFIED | Supplier availability/lot and PCBA process must be confirmed; buy either populated parent or children
PCB-B06-IO/U1 | PCB-B06-IO | 1 | pcs | component_child | R-78HB5.0-0.5 | R-78HB5.0-0.5 | electronics/base-io-b05/manufacturing/b06-io-control01/B06-IO-CONTROL01-BOM.csv | NATIVE_BOM_VERIFIED | Supplier availability/lot and PCBA process must be confirmed; buy either populated parent or children
PCB-B06-IO/U2 | PCB-B06-IO | 1 | pcs | component_child | STM32G030F6P6 | STM32G030F6P6 | electronics/base-io-b05/manufacturing/b06-io-control01/B06-IO-CONTROL01-BOM.csv | NATIVE_BOM_VERIFIED | Supplier availability/lot and PCBA process must be confirmed; buy either populated parent or children
PCB-B06-IO/U3 | PCB-B06-IO | 1 | pcs | component_child | AP2112K-3.3TRG1 | AP2112K-3.3TRG1 | electronics/base-io-b05/manufacturing/b06-io-control01/B06-IO-CONTROL01-BOM.csv | NATIVE_BOM_VERIFIED | Supplier availability/lot and PCBA process must be confirmed; buy either populated parent or children
PCB-B06-LIGHT/C1 | PCB-B06-LIGHT | 1 | pcs | component_child | 100nF | CC0603KRX7R8BB104 | electronics/base-light-b06/manufacturing/bom.csv | NATIVE_BOM_VERIFIED | Supplier availability/lot and PCBA process must be confirmed; buy either populated parent or children
PCB-B06-LIGHT/D1 | PCB-B06-LIGHT | 1 | pcs | component_child | NSVBAT54HT1G | NSVBAT54HT1G | electronics/base-light-b06/manufacturing/bom.csv | NATIVE_BOM_VERIFIED | Supplier availability/lot and PCBA process must be confirmed; buy either populated parent or children
PCB-B06-LIGHT/J1 | PCB-B06-LIGHT | 1 | pcs | component_child | BM03B-GHS-TBT(LF)(SN) | BM03B-GHS-TBT(LF)(SN) | electronics/base-light-b06/manufacturing/bom.csv | NATIVE_BOM_VERIFIED | Supplier availability/lot and PCBA process must be confirmed; buy either populated parent or children
PCB-B06-LIGHT/LED1,LED2,LED3 | PCB-B06-LIGHT | 3 | pcs | component_child | LTST-C170KFKT | LTST-C170KFKT | electronics/base-light-b06/manufacturing/bom.csv | NATIVE_BOM_VERIFIED | Supplier availability/lot and PCBA process must be confirmed; buy either populated parent or children
PCB-B06-LIGHT/Q1 | PCB-B06-LIGHT | 1 | pcs | component_child | DMG2302UK-7 | DMG2302UK-7 | electronics/base-light-b06/manufacturing/bom.csv | NATIVE_BOM_VERIFIED | Supplier availability/lot and PCBA process must be confirmed; buy either populated parent or children
PCB-B06-LIGHT/R1,R2,R3 | PCB-B06-LIGHT | 3 | pcs | component_child | 470Ω | RC0603FR-07470RL | electronics/base-light-b06/manufacturing/bom.csv | NATIVE_BOM_VERIFIED | Supplier availability/lot and PCBA process must be confirmed; buy either populated parent or children
PCB-B06-LIGHT/R4 | PCB-B06-LIGHT | 1 | pcs | component_child | 1kΩ | RC0603FR-071KL | electronics/base-light-b06/manufacturing/bom.csv | NATIVE_BOM_VERIFIED | Supplier availability/lot and PCBA process must be confirmed; buy either populated parent or children
PCB-B06-LIGHT/R5 | PCB-B06-LIGHT | 1 | pcs | component_child | 47kΩ | RC0603FR-0747KL | electronics/base-light-b06/manufacturing/bom.csv | NATIVE_BOM_VERIFIED | Supplier availability/lot and PCBA process must be confirmed; buy either populated parent or children
W01 | BASE | 1 | operation | weld_process | Four continuous 140mm fillets; z5, proposed leg5.0..5.5; postweld datum machining |  | manufacturing.md | DEFINITION_OPEN | WPS, bead profile, end allowance, distortion and joint strength unqualified
EXT-48V-MATE | BASE | 1 | pcs | connector | Phoenix PC5/2 mating spring plug | 1718481 | manufacturing.md | DEFINITION_OPEN | Real ClickLock operation / conductor preparation / cable exit fit
RF-BULKHEAD | BASE | 2 | pcs | connector | Amphenol SMA female-female 50ohm bulkhead | 132170 | manufacturing.md | DEFINITION_OPEN | Current manufacturer drawing and actual nut/tool fit required; GMSL channel/PoC not qualified
POWER-M3-LUG | BASE | 2 | pcs | terminal_candidate | TE M3 ring lug; 1.5..2.5mm2; plate0.79mm | 165295 | manufacturing.md | DEFINITION_OPEN | Actual tolerance, crimp tool, wire gauge/current/length, barrel rotation and boot required
BOND-M3-LUG | BASE | 1 | pcs | terminal_candidate | TE M3 ring lug at J6; never use power return as chassis bond | 165295 | manufacturing.md | DEFINITION_OPEN | Bond conductor and topology to external box require definition
STUD-HALF-NUT | BASE | 3 | pcs | hardware_candidate | M3 ISO4035 thin nut; nominal1.8mm; no extra washer |  | manufacturing.md | DEFINITION_OPEN | Not released: tolerance/full-thread engagement/retention/anti-rotation and torque sample tests
FRAME-BOND-LUG | BASE | 1 | pcs | terminal_candidate | TE M6 ring lug at dedicated frame hole | 165299 | manufacturing.md | DEFINITION_OPEN | Drawing, cross section, crimp and grounding contact preparation required
FRAME-BOND-SCREW | BASE | 1 | pcs | hardware_candidate | M6 screw + contact locking hardware |  | manufacturing.md | DEFINITION_OPEN | Length/stack/thread engagement and MCAD/tool clearance must be selected before purchase
H-POWER | BASE | 1 | assembly | harness_open | 48V + return from J4/J5 to module boundary |  | manufacturing.md | DEFINITION_OPEN | Gauge/current/length/ends/boots/clamps unknown; no arm harness required for base dummy load
H-BOND | BASE | 1 | assembly | harness_open | J6 to metal frame and external protective-bond boundary |  | manufacturing.md | DEFINITION_OPEN | Topology/length/cross section and low resistance acceptance not frozen
H-ECAT | BASE | 1 | assembly | harness_open | Internal shielded Ethernet J2 to module boundary; two-ended base loopback test |  | manufacturing.md | DEFINITION_OPEN | Exact cable/plug/length; shield termination and fixed bend radius to be checked
H-RF | BASE | 2 | assembly | harness_open | 50ohm coax from bulkhead to module-side test connector |  | manufacturing.md | DEFINITION_OPEN | Connector family/length/route/minimum bend/channel budget/PoC unknown
H-LAMP | BASE | 1 | assembly | harness_open | Internal short lead only: base board to JST GH 1=5V 2=PWM 3=GND | GHR-03V-S + 3xSSHL-002T-P0.2 | manufacturing.md | DEFINITION_OPEN | No separate desk-box5V lead; local converter/controller candidate; actual length/colors/crimp/route unknown
H-UART | BASE | 1 | assembly | harness_open | J8 internal GH3 UART to external box;3.3V TX/RX/GND | GHR-03V-S + 3xSSHL-002T-P0.2 | manufacturing.md | DEFINITION_OPEN | No power pin; actual controller/isolation/length/clamps/route unknown
H-SWD | BASE | 1 | assembly | harness_open | J9 GH5 service lead: GND/3V3 ref/SWDIO/SWCLK/NRST | GHR-05V-S + 5xSSHL-002T-P0.2 | manufacturing.md | DEFINITION_OPEN | Service accessory;3V3 reference only; no backfeed; length/route/actual debug connector pending
LIGHT-SHIM | BASE | 2 | pcs | optical_open | Soft optical-support pad; current nominal support gap at least0.4mm |  | manufacturing.md | DEFINITION_OPEN | Material/thickness/compression/translucency measured on actual printed lens
CABLE-RESTRAINT | BASE | 1 | set | consumable_open | Rounded ties / saddles at existing carrier ears; wire boots and insulated separation |  | manufacturing.md | DEFINITION_OPEN | Count/position/tool and pull-force criteria after actual harness route
FINISH | BASE | 1 | operation | finish_open | Deburr, corrosion protection; mask bond faces/threads/datum seats |  | manufacturing.md | DEFINITION_OPEN | Coating and weld preparation agreed with supplier; no coating in conductive bond interface

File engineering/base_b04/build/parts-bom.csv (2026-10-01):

id | category | quantity | material | process | mass_kg
B04-101-DECK | custom | 1 | 6061-T651 | CNC profile + mill + drill/tap | 1.5805939480633266
B04-102-CPLATE-L | custom | 1 | S355 | Profile cut oversize; finish mill + drill/tap | 0.9224648072629437
B04-102-CPLATE-R | custom | 1 | S355 | Profile cut oversize; finish mill + drill/tap | 0.9224648072629436
B04-103-BRIDGE | custom | 1 | 6061-T651 | CNC mill + drill/tap | 0.8718565283264427
B04-104-FLANGE | custom | 1 | 6061-T651 | CNC turn/mill + drill/tap; champagne anodize, mask mating faces | 0.5473882765280974
B04-105-POST-1 | custom | 1 | 6061-T651 | Turn + drill/tap | 0.029705693760766105
B04-105-POST-2 | custom | 1 | 6061-T651 | Turn + drill/tap | 0.029705693760766098
B04-105-POST-3 | custom | 1 | 6061-T651 | Turn + drill/tap | 0.029705693760766108
B04-105-POST-4 | custom | 1 | 6061-T651 | Turn + drill/tap | 0.029705693760766115
B04-106-TOPPAD--1 | custom | 1 | silicone | Knife/waterjet cut | 0.01521283096792931
B04-107-PRESSPAD--1 | custom | 1 | 6061-T651 | CNC mill/drill/tap | 0.13575408248376988
B04-108-LOWPAD--1 | custom | 1 | silicone | Knife/waterjet cut | 0.014472230967929307
B04-109-FOOT-CAGE--1--1 | custom | 1 | PETG | FDM; 0.2 layer, 4 walls, solid around screws | 0.003681650645783561
B04-109-FOOT-CAGE--1-1 | custom | 1 | PETG | FDM; 0.2 layer, 4 walls, solid around screws | 0.0036816506457834847
B04-106-TOPPAD-1 | custom | 1 | silicone | Knife/waterjet cut | 0.01521283096792931
B04-107-PRESSPAD-1 | custom | 1 | 6061-T651 | CNC mill/drill/tap | 0.13575408248376988
B04-108-LOWPAD-1 | custom | 1 | silicone | Knife/waterjet cut | 0.014472230967929307
B04-109-FOOT-CAGE-1--1 | custom | 1 | PETG | FDM; 0.2 layer, 4 walls, solid around screws | 0.0036816506457835606
B04-109-FOOT-CAGE-1-1 | custom | 1 | PETG | FDM; 0.2 layer, 4 walls, solid around screws | 0.003681650645783486
B04-201-CRADLE-L | custom | 1 | 6061-T651 | CNC profile + drill/tap | 0.2238963823106716
B04-201-CRADLE-R | custom | 1 | 6061-T651 | CNC profile + drill/tap | 0.22389638231067172
B04-202-TRAY | custom | 1 | 6061-T651 | CNC profile + drill/tap | 0.6458674541106519
B04-203-STOP-REAR | custom | 1 | 6061-T651 | Mill + drill | 0.06892558813196618
B04-203-STOP-FRONT | custom | 1 | 6061-T651 | Mill + drill | 0.06892558813196618
HW-COVER-POST-0 | hardware | 1 | brass | Purchase M3 M/F hex AF5.5 x10; male6; female depth>=6 | 0.0028445943381010482
HW-COVER-POST-1 | hardware | 1 | brass | Purchase M3 M/F hex AF5.5 x10; male6; female depth>=6 | 0.0028445943381010482
HW-COVER-POST-2 | hardware | 1 | brass | Purchase M3 M/F hex AF5.5 x10; male6; female depth>=6 | 0.0028445943381010482
HW-COVER-POST-3 | hardware | 1 | brass | Purchase M3 M/F hex AF5.5 x10; male6; female depth>=6 | 0.0028445943381010482
HW-COVER-POST-4 | hardware | 1 | brass | Purchase M3 M/F hex AF5.5 x10; male6; female depth>=6 | 0.002844594338101049
HW-COVER-POST-5 | hardware | 1 | brass | Purchase M3 M/F hex AF5.5 x10; male6; female depth>=6 | 0.002844594338101049
HW-PCB-POST-0 | hardware | 1 | brass | Purchase M3 M/F hex AF5.5 x9; male6 | 0.0020854795242416955
HW-PCB-POST-1 | hardware | 1 | brass | Purchase M3 M/F hex AF5.5 x9; male6 | 0.0020854795242416955
HW-PCB-POST-2 | hardware | 1 | brass | Purchase M3 M/F hex AF5.5 x9; male6 | 0.0020854795242416955
HW-PCB-POST-3 | hardware | 1 | brass | Purchase M3 M/F hex AF5.5 x9; male6 | 0.0020854795242416955
B04-301-COVER-REAR | custom | 1 | PETG | FDM; 0.2mm layer; 4 walls; supports under roof | 0.12138910894894502
B04-301-COVER-FRONT | custom | 1 | PETG | FDM; 0.2mm layer; 4 walls; supports under roof | 0.19703306210851107
B04-302-LIGHT-LENS | custom | 1 | PETG | Translucent amber PETG prototype; later frosted polycarbonate, no optical performance claim | 0.001224342668698023
ENV-PCB | envelope | 1 | FR4 | Actual KiCad drilled board, see electronics/base-b04
ENV-CONTROLLER | envelope | 1 | FR4 | Controller volume gauge; electronics not yet designed
HW-THRUST-FOOT--1 | hardware | 1 | steel | Ganter DIN6311-25-S envelope; articulation not simulated | 0.03710323025650787
HW-THRUST-SCREW--1 | hardware | 1 | steel | Ganter DIN6332-M12-100-SK; AF6 tool socket shown, depth8 allocation, threads/neck simplified | 0.07936585985277411
HW-THRUST-FOOT-1 | hardware | 1 | steel | Ganter DIN6311-25-S envelope; articulation not simulated | 0.03710323025650787
HW-THRUST-SCREW-1 | hardware | 1 | steel | Ganter DIN6332-M12-100-SK; AF6 tool socket shown, depth8 allocation, threads/neck simplified | 0.07936585985277411
HW-LIGHT-INSERT--22 | hardware | 1 | brass | ruthex RX-M2x4, OD3.6 L4 from vendor STEP; knurl/thread simplified | 0.00022831524609963818
HW-M2-LIGHT--22 | fastener | 1 | steel | Purchase ISO4762 cap screw M2x6; class8.8 minimum; washer t0.3 | 0.0003465115185491978
HW-LIGHT-INSERT-22 | hardware | 1 | brass | ruthex RX-M2x4, OD3.6 L4 from vendor STEP; knurl/thread simplified | 0.00022831524609963818
HW-M2-LIGHT-22 | fastener | 1 | steel | Purchase ISO4762 cap screw M2x6; class8.8 minimum; washer t0.3 | 0.00034651151854919786
HW-M8-FLANGE-0 | fastener | 1 | steel | Purchase ISO4762 cap screw M8x25; class8.8 minimum; washer t1.6 | 0.01891944595931244
HW-M8-DECK-0 | fastener | 1 | steel | Purchase ISO4762 cap screw M8x16; class8.8 minimum | 0.013474186244698332
HW-M8-FLANGE-1 | fastener | 1 | steel | Purchase ISO4762 cap screw M8x25; class8.8 minimum; washer t1.6 | 0.01891944595931244
HW-M8-DECK-1 | fastener | 1 | steel | Purchase ISO4762 cap screw M8x16; class8.8 minimum | 0.013474186244698332
HW-M8-FLANGE-2 | fastener | 1 | steel | Purchase ISO4762 cap screw M8x25; class8.8 minimum; washer t1.6 | 0.01891944595931244
HW-M8-DECK-2 | fastener | 1 | steel | Purchase ISO4762 cap screw M8x16; class8.8 minimum | 0.013474186244698332
HW-M8-FLANGE-3 | fastener | 1 | steel | Purchase ISO4762 cap screw M8x25; class8.8 minimum; washer t1.6 | 0.01891944595931244
HW-M8-DECK-3 | fastener | 1 | steel | Purchase ISO4762 cap screw M8x16; class8.8 minimum | 0.013474186244698332
HW-M6-DECK--1-0 | fastener | 1 | steel | Purchase ISO4762 cap screw M6x25; class8.8 minimum; washer t1.6 | 0.009701593326916617
HW-M6-DECK--1-1 | fastener | 1 | steel | Purchase ISO4762 cap screw M6x25; class8.8 minimum; washer t1.6 | 0.009701593326916617
HW-M6-DECK--1-2 | fastener | 1 | steel | Purchase ISO4762 cap screw M6x25; class8.8 minimum; washer t1.6 | 0.009701593326916618
HW-M8-BRIDGE--1-0 | fastener | 1 | steel | Purchase ISO4762 cap screw M8x25; class8.8 minimum; washer t1.6 | 0.018919445959312445
HW-M8-BRIDGE--1-1 | fastener | 1 | steel | Purchase ISO4762 cap screw M8x25; class8.8 minimum; washer t1.6 | 0.018919445959312442
HW-M6-CRADLE--1-0 | fastener | 1 | steel | Purchase ISO4762 cap screw M6x16; class8.8 minimum; washer t1.6 | 0.0077040116381315495
HW-M6-CRADLE--1-1 | fastener | 1 | steel | Purchase ISO4762 cap screw M6x16; class8.8 minimum; washer t1.6 | 0.0077040116381315495
HW-M3-CAGE--1--1 | fastener | 1 | steel | Purchase ISO4762 cap screw M3x14; class8.8 minimum | 0.0012598642890720023
HW-M3-CAGE--1-1 | fastener | 1 | steel | Purchase ISO4762 cap screw M3x14; class8.8 minimum | 0.0012598642890720025
HW-M6-DECK-1-0 | fastener | 1 | steel | Purchase ISO4762 cap screw M6x25; class8.8 minimum; washer t1.6 | 0.009701593326916617
HW-M6-DECK-1-1 | fastener | 1 | steel | Purchase ISO4762 cap screw M6x25; class8.8 minimum; washer t1.6 | 0.009701593326916617
HW-M6-DECK-1-2 | fastener | 1 | steel | Purchase ISO4762 cap screw M6x25; class8.8 minimum; washer t1.6 | 0.009701593326916618
HW-M8-BRIDGE-1-0 | fastener | 1 | steel | Purchase ISO4762 cap screw M8x25; class8.8 minimum; washer t1.6 | 0.018919445959312445
HW-M8-BRIDGE-1-1 | fastener | 1 | steel | Purchase ISO4762 cap screw M8x25; class8.8 minimum; washer t1.6 | 0.018919445959312442
HW-M6-CRADLE-1-0 | fastener | 1 | steel | Purchase ISO4762 cap screw M6x16; class8.8 minimum; washer t1.6 | 0.0077040116381315495
HW-M6-CRADLE-1-1 | fastener | 1 | steel | Purchase ISO4762 cap screw M6x16; class8.8 minimum; washer t1.6 | 0.0077040116381315495
HW-M3-CAGE-1--1 | fastener | 1 | steel | Purchase ISO4762 cap screw M3x14; class8.8 minimum | 0.0012598642890720023
HW-M3-CAGE-1-1 | fastener | 1 | steel | Purchase ISO4762 cap screw M3x14; class8.8 minimum | 0.0012598642890720025
HW-M3-COVER-TOP-0 | fastener | 1 | steel | Purchase ISO4762 cap screw M3x8; class8.8 minimum; washer t0.5 | 0.0010502415192612234
HW-M3-COVER-TOP-1 | fastener | 1 | steel | Purchase ISO4762 cap screw M3x8; class8.8 minimum; washer t0.5 | 0.0010502415192612234
HW-M3-COVER-TOP-2 | fastener | 1 | steel | Purchase ISO4762 cap screw M3x8; class8.8 minimum; washer t0.5 | 0.0010502415192612234
HW-M3-COVER-TOP-3 | fastener | 1 | steel | Purchase ISO4762 cap screw M3x8; class8.8 minimum; washer t0.5 | 0.0010502415192612234
HW-M3-COVER-TOP-4 | fastener | 1 | steel | Purchase ISO4762 cap screw M3x8; class8.8 minimum; washer t0.5 | 0.001050241519261224
HW-M3-COVER-TOP-5 | fastener | 1 | steel | Purchase ISO4762 cap screw M3x8; class8.8 minimum; washer t0.5 | 0.001050241519261224
HW-M3-PCB-0 | fastener | 1 | steel | Purchase ISO4762 cap screw M3x8; class8.8 minimum; washer t0.5 | 0.0010502415192612234
HW-M3-PCB-1 | fastener | 1 | steel | Purchase ISO4762 cap screw M3x8; class8.8 minimum; washer t0.5 | 0.0010502415192612234
HW-M3-PCB-2 | fastener | 1 | steel | Purchase ISO4762 cap screw M3x8; class8.8 minimum; washer t0.5 | 0.0010502415192612238
HW-M3-PCB-3 | fastener | 1 | steel | Purchase ISO4762 cap screw M3x8; class8.8 minimum; washer t0.5 | 0.0010502415192612238
HW-M4-TRAY--124-140 | fastener | 1 | steel | Purchase ISO4762 cap screw M4x12; class8.8 minimum | 0.0022453224586102593
HW-M4-TRAY--124-250 | fastener | 1 | steel | Purchase ISO4762 cap screw M4x12; class8.8 minimum | 0.0022453224586102593
HW-M4-TRAY-124-140 | fastener | 1 | steel | Purchase ISO4762 cap screw M4x12; class8.8 minimum | 0.0022453224586102593
HW-M4-TRAY-124-250 | fastener | 1 | steel | Purchase ISO4762 cap screw M4x12; class8.8 minimum | 0.0022453224586102593
HW-M4-STOP--100-112 | fastener | 1 | steel | Purchase ISO4762 cap screw M4x16; class8.8 minimum | 0.0026399064959011344
HW-M4-STOP--100-278 | fastener | 1 | steel | Purchase ISO4762 cap screw M4x16; class8.8 minimum | 0.0026399064959011405
HW-M4-STOP-100-112 | fastener | 1 | steel | Purchase ISO4762 cap screw M4x16; class8.8 minimum | 0.002639906495901134
HW-M4-STOP-100-278 | fastener | 1 | steel | Purchase ISO4762 cap screw M4x16; class8.8 minimum | 0.00263990649590114
B04-401-INTERFACE-CARRIER | custom | 1 | 6061-T651 | Machine from angle billet; internal filletR2 allowance; drill/tap | 0.12575451253123943
HW-M4-CARRIER--80--18 | fastener | 1 | steel | Purchase ISO4762 cap screw M4x10; class8.8 minimum; washer t0.8 | 0.0023686299702636586
HW-M4-CARRIER--80--6 | fastener | 1 | steel | Purchase ISO4762 cap screw M4x10; class8.8 minimum; washer t0.8 | 0.0023686299702636586
HW-M4-CARRIER-80--18 | fastener | 1 | steel | Purchase ISO4762 cap screw M4x10; class8.8 minimum; washer t0.8 | 0.002368629970263658
HW-M4-CARRIER-80--6 | fastener | 1 | steel | Purchase ISO4762 cap screw M4x10; class8.8 minimum; washer t0.8 | 0.002368629970263658
HW-INTERFACE-POST--52--59 | hardware | 1 | brass | M3 F/F hex AF5.5 x10; each female depth>=4.5 | 0.0023171994713796617
HW-M3-INTERFACE-BACK--52--59 | fastener | 1 | steel | Purchase ISO4762 cap screw M3x8; class8.8 minimum; washer t0.5 | 0.001050241519261224
HW-M3-INTERFACE-FRONT--52--59 | fastener | 1 | steel | Purchase ISO4762 cap screw M3x6; class8.8 minimum; washer t0.5 | 0.0009392647587731642
HW-INTERFACE-POST--52--15 | hardware | 1 | brass | M3 F/F hex AF5.5 x10; each female depth>=4.5 | 0.0023171994713796617
HW-M3-INTERFACE-BACK--52--15 | fastener | 1 | steel | Purchase ISO4762 cap screw M3x8; class8.8 minimum; washer t0.5 | 0.0010502415192612238
HW-M3-INTERFACE-FRONT--52--15 | fastener | 1 | steel | Purchase ISO4762 cap screw M3x6; class8.8 minimum; washer t0.5 | 0.0009392647587731641
HW-INTERFACE-POST-52--59 | hardware | 1 | brass | M3 F/F hex AF5.5 x10; each female depth>=4.5 | 0.0023171994713796617
HW-M3-INTERFACE-BACK-52--59 | fastener | 1 | steel | Purchase ISO4762 cap screw M3x8; class8.8 minimum; washer t0.5 | 0.001050241519261224
HW-M3-INTERFACE-FRONT-52--59 | fastener | 1 | steel | Purchase ISO4762 cap screw M3x6; class8.8 minimum; washer t0.5 | 0.0009392647587731642
HW-INTERFACE-POST-52--15 | hardware | 1 | brass | M3 F/F hex AF5.5 x10; each female depth>=4.5 | 0.0023171994713796617
HW-M3-INTERFACE-BACK-52--15 | fastener | 1 | steel | Purchase ISO4762 cap screw M3x8; class8.8 minimum; washer t0.5 | 0.0010502415192612238
HW-M3-INTERFACE-FRONT-52--15 | fastener | 1 | steel | Purchase ISO4762 cap screw M3x6; class8.8 minimum; washer t0.5 | 0.0009392647587731641
HW-M3-PORT-HOOD--61.5 | fastener | 1 | steel | Purchase ISO4762 cap screw M3x35; class8.8 minimum; washer t0.5 | 0.0025484277858500264
HW-M3-PORT-HOOD-61.5 | fastener | 1 | steel | Purchase ISO4762 cap screw M3x35; class8.8 minimum; washer t0.5 | 0.0025484277858500264
B04-402-PORT-HOOD | custom | 1 | PETG | FDM U-hood, 2mm walls; post-drill mounting holes | 0.03869241153557974
GUIDE-AF6-CLAMP-KEY | guide | 1 | steel | Removable AF6 long key: insert from below; side frame bolts do not tighten the desk
ENV-DESK | environment | 1 | wood | Test environment; not part of BOM
ENV-WALL | environment | 1 | wall | Clearance plane at y=-48
PCB-C1 | component | 1 | FR4 | Purchased component outer envelope; see PCB BOM
PCB-C2 | component | 1 | FR4 | Purchased component outer envelope; see PCB BOM
PCB-C3 | component | 1 | FR4 | Purchased component outer envelope; see PCB BOM
PCB-C4 | component | 1 | FR4 | Purchased component outer envelope; see PCB BOM
PCB-C5 | component | 1 | FR4 | Purchased component outer envelope; see PCB BOM
PCB-C6 | component | 1 | FR4 | Purchased component outer envelope; see PCB BOM
PCB-C7 | component | 1 | FR4 | Purchased component outer envelope; see PCB BOM
PCB-D1 | component | 1 | FR4 | Purchased component outer envelope; see PCB BOM
PCB-D2 | component | 1 | FR4 | Purchased component outer envelope; see PCB BOM
PCB-D3 | component | 1 | FR4 | Purchased component outer envelope; see PCB BOM
PCB-D4 | component | 1 | FR4 | Purchased component outer envelope; see PCB BOM
PCB-F1 | component | 1 | FR4 | Purchased component outer envelope; see PCB BOM
PCB-J1 | component | 1 | FR4 | Purchased component outer envelope; see PCB BOM
PCB-J2 | component | 1 | FR4 | Purchased component outer envelope; see PCB BOM
PCB-J3 | component | 1 | FR4 | Purchased component outer envelope; see PCB BOM
PCB-L1 | component | 1 | FR4 | Purchased component outer envelope; see PCB BOM
PCB-Q1 | component | 1 | FR4 | Purchased component outer envelope; see PCB BOM
PCB-Q2 | component | 1 | FR4 | Purchased component outer envelope; see PCB BOM
PCB-R1 | component | 1 | FR4 | Purchased component outer envelope; see PCB BOM
PCB-R10 | component | 1 | FR4 | Purchased component outer envelope; see PCB BOM
PCB-R11 | component | 1 | FR4 | Purchased component outer envelope; see PCB BOM
PCB-R12 | component | 1 | FR4 | Purchased component outer envelope; see PCB BOM
PCB-R13 | component | 1 | FR4 | Purchased component outer envelope; see PCB BOM
PCB-R14 | component | 1 | FR4 | Purchased component outer envelope; see PCB BOM
PCB-R16 | component | 1 | FR4 | Purchased component outer envelope; see PCB BOM
PCB-R17 | component | 1 | FR4 | Purchased component outer envelope; see PCB BOM
PCB-R18 | component | 1 | FR4 | Purchased component outer envelope; see PCB BOM
PCB-R19 | component | 1 | FR4 | Purchased component outer envelope; see PCB BOM
PCB-R2 | component | 1 | FR4 | Purchased component outer envelope; see PCB BOM
PCB-R20 | component | 1 | FR4 | Purchased component outer envelope; see PCB BOM
PCB-R22 | component | 1 | FR4 | Purchased component outer envelope; see PCB BOM
PCB-R3 | component | 1 | FR4 | Purchased component outer envelope; see PCB BOM
PCB-R4 | component | 1 | FR4 | Purchased component outer envelope; see PCB BOM
PCB-R5 | component | 1 | FR4 | Purchased component outer envelope; see PCB BOM
PCB-R6 | component | 1 | FR4 | Purchased component outer envelope; see PCB BOM
PCB-R7 | component | 1 | FR4 | Purchased component outer envelope; see PCB BOM
PCB-R8 | component | 1 | FR4 | Purchased component outer envelope; see PCB BOM
PCB-U1 | component | 1 | FR4 | Purchased component outer envelope; see PCB BOM
PCB-U2 | component | 1 | FR4 | Purchased component outer envelope; see PCB BOM
PCB-U3 | component | 1 | FR4 | Purchased component outer envelope; see PCB BOM
PCB-J1_mating_plug_extension | component | 1 | FR4 | catalogue reference/clearance envelope; not exact mating connector vendor CAD
PCB-J2_mating_plug_extension | component | 1 | FR4 | catalogue reference/clearance envelope; not exact mating connector vendor CAD
PCB-J3_mating_plug_extension | component | 1 | FR4 | catalogue reference/clearance envelope; not exact mating connector vendor CAD
PCB-J1_mated_height_reservation | component | 1 | FR4 | mated reference height reservation, not mass-bearing body
PCB-J2_mated_height_reservation | component | 1 | FR4 | mated reference height reservation, not mass-bearing body
PCB-J3_mated_height_reservation | component | 1 | FR4 | mated reference height reservation, not mass-bearing body
PCB-pin-J1-1 | component | 1 | steel | Trimmed lead allocation from native PTH readback
PCB-pin-J1-2 | component | 1 | steel | Trimmed lead allocation from native PTH readback
PCB-pin-J2-1 | component | 1 | steel | Trimmed lead allocation from native PTH readback
PCB-pin-J2-2 | component | 1 | steel | Trimmed lead allocation from native PTH readback
PCB-pin-J2-3 | component | 1 | steel | Trimmed lead allocation from native PTH readback
PCB-pin-J2-4 | component | 1 | steel | Trimmed lead allocation from native PTH readback
PCB-pin-J3-1 | component | 1 | steel | Trimmed lead allocation from native PTH readback
PCB-pin-J3-2 | component | 1 | steel | Trimmed lead allocation from native PTH readback
PCB-pin-J3-3 | component | 1 | steel | Trimmed lead allocation from native PTH readback
PCB-pin-J3-4 | component | 1 | steel | Trimmed lead allocation from native PTH readback
PCB-pin-U2-1 | component | 1 | steel | Trimmed lead allocation from native PTH readback
PCB-pin-U2-2 | component | 1 | steel | Trimmed lead allocation from native PTH readback
PCB-pin-U2-3 | component | 1 | steel | Trimmed lead allocation from native PTH readback
PCB-pin-U2-4 | component | 1 | steel | Trimmed lead allocation from native PTH readback
PCB-pin-U3-1 | component | 1 | steel | Trimmed lead allocation from native PTH readback
PCB-pin-U3-2 | component | 1 | steel | Trimmed lead allocation from native PTH readback
PCB-pin-U3-3 | component | 1 | steel | Trimmed lead allocation from native PTH readback
PCB-pin-U3-4 | component | 1 | steel | Trimmed lead allocation from native PTH readback
LIGHT-BOARD-0 | component | 1 | FR4 | Native light PCB or original LED/pad reference; see base-light-b04
LIGHT-LED-1 | component | 1 | FR4 | Native light PCB or original LED/pad reference; see base-light-b04
LIGHT-LED-2 | component | 1 | FR4 | Native light PCB or original LED/pad reference; see base-light-b04
LIGHT-LED-3 | component | 1 | FR4 | Native light PCB or original LED/pad reference; see base-light-b04
LIGHT-PAD-4 | component | 1 | FR4 | Native light PCB or original LED/pad reference; see base-light-b04
LIGHT-PAD-5 | component | 1 | FR4 | Native light PCB or original LED/pad reference; see base-light-b04
LIGHT-PAD-6 | component | 1 | FR4 | Native light PCB or original LED/pad reference; see base-light-b04
LIGHT-PAD-7 | component | 1 | FR4 | Native light PCB or original LED/pad reference; see base-light-b04
BRI-BRI01_PCB-0 | component | 1 | FR4 | actual board outline and all current native footprint drills; no copper thickness geometry
BRI-J1_shell_reference-1 | component | 1 | FR4 | Original shell/cavity abstraction; cavity not controlled mating geometry
BRI-J1_spring_reservation_-8.65-2 | component | 1 | FR4 | Bounds derived from private vendor STEP; rectangular envelope, not metal distribution
BRI-J1_spring_reservation_7.5-3 | component | 1 | FR4 | Bounds derived from private vendor STEP; rectangular envelope, not metal distribution
BRI-J1_tail_0-4 | component | 1 | FR4 | Physical pin planning; alloy/contact details omitted
BRI-J1_tail_1-5 | component | 1 | FR4 | Physical pin planning; alloy/contact details omitted
BRI-J1_tail_2-6 | component | 1 | FR4 | Physical pin planning; alloy/contact details omitted
BRI-J1_tail_3-7 | component | 1 | FR4 | Physical pin planning; alloy/contact details omitted
BRI-J1_tail_4-8 | component | 1 | FR4 | Physical pin planning; alloy/contact details omitted
BRI-J1_tail_5-9 | component | 1 | FR4 | Physical pin planning; alloy/contact details omitted
BRI-J1_tail_6-10 | component | 1 | FR4 | Physical pin planning; alloy/contact details omitted
BRI-J1_tail_7-11 | component | 1 | FR4 | Physical pin planning; alloy/contact details omitted
BRI-J1_tail_8-12 | component | 1 | FR4 | Physical pin planning; alloy/contact details omitted
BRI-J1_tail_9-13 | component | 1 | FR4 | Physical pin planning; alloy/contact details omitted
BRI-J2_shell_reference-14 | component | 1 | FR4 | Original shell/cavity abstraction; cavity not controlled mating geometry
BRI-J2_spring_reservation_-8.65-15 | component | 1 | FR4 | Bounds derived from private vendor STEP; rectangular envelope, not metal distribution
BRI-J2_spring_reservation_7.5-16 | component | 1 | FR4 | Bounds derived from private vendor STEP; rectangular envelope, not metal distribution
BRI-J2_tail_0-17 | component | 1 | FR4 | Physical pin planning; alloy/contact details omitted
BRI-J2_tail_1-18 | component | 1 | FR4 | Physical pin planning; alloy/contact details omitted
BRI-J2_tail_2-19 | component | 1 | FR4 | Physical pin planning; alloy/contact details omitted
BRI-J2_tail_3-20 | component | 1 | FR4 | Physical pin planning; alloy/contact details omitted
BRI-J2_tail_4-21 | component | 1 | FR4 | Physical pin planning; alloy/contact details omitted
BRI-J2_tail_5-22 | component | 1 | FR4 | Physical pin planning; alloy/contact details omitted
BRI-J2_tail_6-23 | component | 1 | FR4 | Physical pin planning; alloy/contact details omitted
BRI-J2_tail_7-24 | component | 1 | FR4 | Physical pin planning; alloy/contact details omitted
BRI-J2_tail_8-25 | component | 1 | FR4 | Physical pin planning; alloy/contact details omitted
BRI-J2_tail_9-26 | component | 1 | FR4 | Physical pin planning; alloy/contact details omitted
BRI-J3_header_reference-27 | component | 1 | FR4 | Original catalogue-envelope/cavity abstraction; exact6-pin footprint independently audited
BRI-J3_tail_0-28 | component | 1 | FR4 | Physical pin planning; alloy/contact details omitted
BRI-J3_tail_1-29 | component | 1 | FR4 | Physical pin planning; alloy/contact details omitted
BRI-J3_tail_2-30 | component | 1 | FR4 | Physical pin planning; alloy/contact details omitted
BRI-J3_tail_3-31 | component | 1 | FR4 | Physical pin planning; alloy/contact details omitted
BRI-J3_tail_4-32 | component | 1 | FR4 | Physical pin planning; alloy/contact details omitted
BRI-J3_tail_5-33 | component | 1 | FR4 | Physical pin planning; alloy/contact details omitted
BRI-J4_M3_stud-34 | component | 1 | FR4 | Nominal manufacturer dimensions; no thread helix.0.5mm stand-off included
BRI-J4_lug_nut_reservation-35 | component | 1 | FR4 | M3 ring/nut upper envelope; exact wire lug and insulation part not yet selected
BRI-J4_tail_0-36 | component | 1 | FR4 | Physical pin planning; alloy/contact details omitted
BRI-J4_tail_1-37 | component | 1 | FR4 | Physical pin planning; alloy/contact details omitted
BRI-J4_tail_2-38 | component | 1 | FR4 | Physical pin planning; alloy/contact details omitted
BRI-J4_tail_3-39 | component | 1 | FR4 | Physical pin planning; alloy/contact details omitted
BRI-J5_M3_stud-40 | component | 1 | FR4 | Nominal manufacturer dimensions; no thread helix.0.5mm stand-off included
BRI-J5_lug_nut_reservation-41 | component | 1 | FR4 | M3 ring/nut upper envelope; exact wire lug and insulation part not yet selected
BRI-J5_tail_0-42 | component | 1 | FR4 | Physical pin planning; alloy/contact details omitted
BRI-J5_tail_1-43 | component | 1 | FR4 | Physical pin planning; alloy/contact details omitted
BRI-J5_tail_2-44 | component | 1 | FR4 | Physical pin planning; alloy/contact details omitted
BRI-J5_tail_3-45 | component | 1 | FR4 | Physical pin planning; alloy/contact details omitted
BRI-J6_M3_stud-46 | component | 1 | FR4 | Nominal manufacturer dimensions; no thread helix.0.5mm stand-off included
BRI-J6_lug_nut_reservation-47 | component | 1 | FR4 | M3 ring/nut upper envelope; exact wire lug and insulation part not yet selected
BRI-J6_tail_0-48 | component | 1 | FR4 | Physical pin planning; alloy/contact details omitted
BRI-J6_tail_1-49 | component | 1 | FR4 | Physical pin planning; alloy/contact details omitted
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

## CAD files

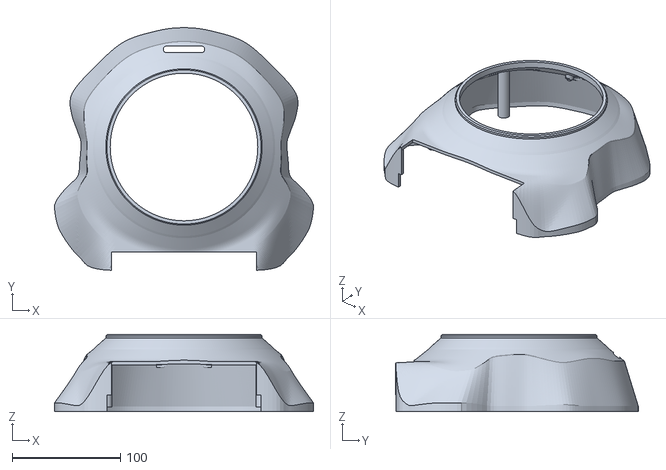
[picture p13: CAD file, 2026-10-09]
engineering/base_b06/build/exterior/print-parts/B06-301-MAIN-SHIELD.stl
238.8 x 223.7 x 71.0

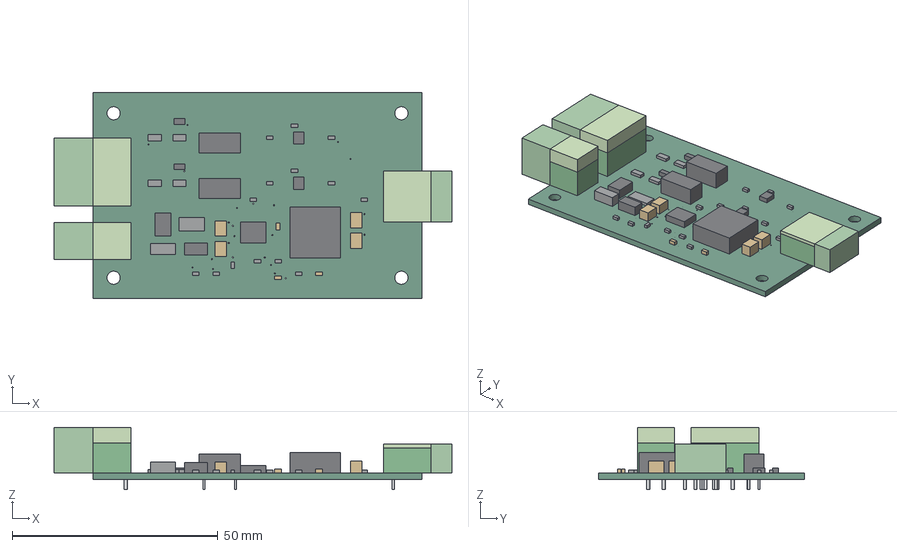
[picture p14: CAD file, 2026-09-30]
engineering/electronics/base-b04/mechanical/base-b04-assembly.step
96.8 x 50.0 x 15.2 mm
PCB_drilled_native
C1
C2
C3
C4
C5
C6
C7
D1
D2
D3
D4
F1
J1
J2
J3
L1
Q1
Q2
R1
R10
R11
R12
R13
R14
R16
R17
R18
R19
R2
R20
R22
R3
R4
R5
R6
R7
R8
U1
U2
U3
pin_J1_1
pin_J1_2
pin_J2_1
pin_J2_2
pin_J2_3
pin_J2_4
pin_J3_1
pin_J3_2
pin_J3_3
pin_J3_4
pin_U2_1
pin_U2_2
pin_U2_3
pin_U2_4
pin_U3_1
pin_U3_2
pin_U3_3
pin_U3_4
J1_mating_plug_extension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

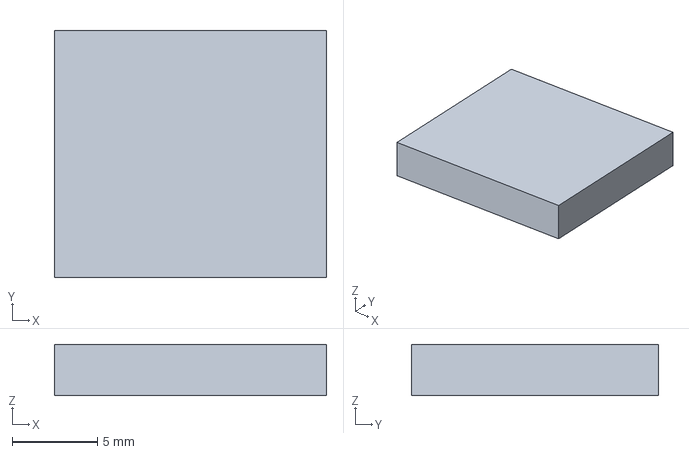
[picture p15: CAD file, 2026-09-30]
engineering/electronics/base-light-b04/mechanical/wire-reservation-only-assembly.step
16.0 x 14.5 x 3.00 mm

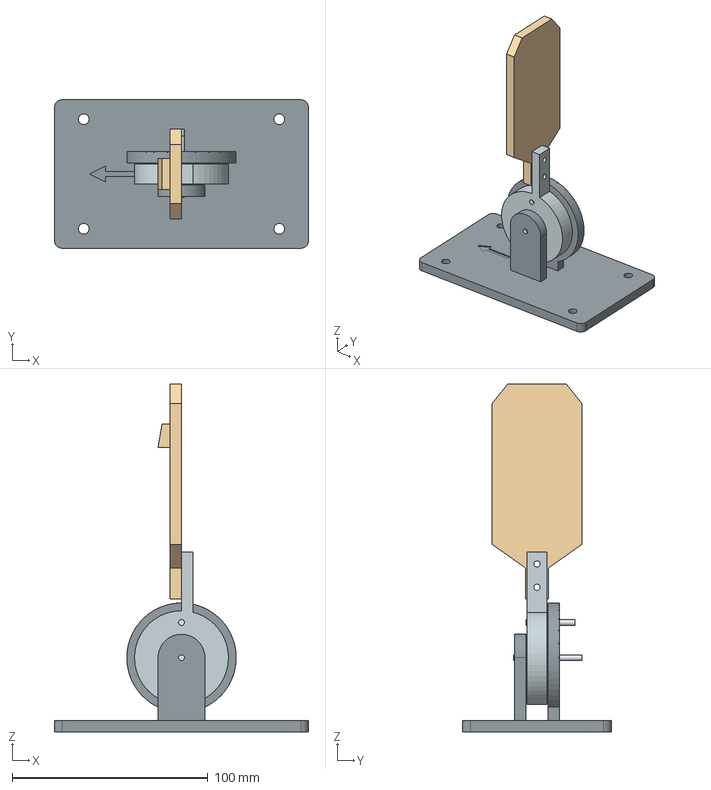
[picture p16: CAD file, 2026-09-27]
engineering/generated/finger-fixture/STEP/assembly-upper-q090p000.step
130.0 x 76.0 x 178.0 mm
base
rotor
upper
axis_reference_only
stop_pin_reference_only

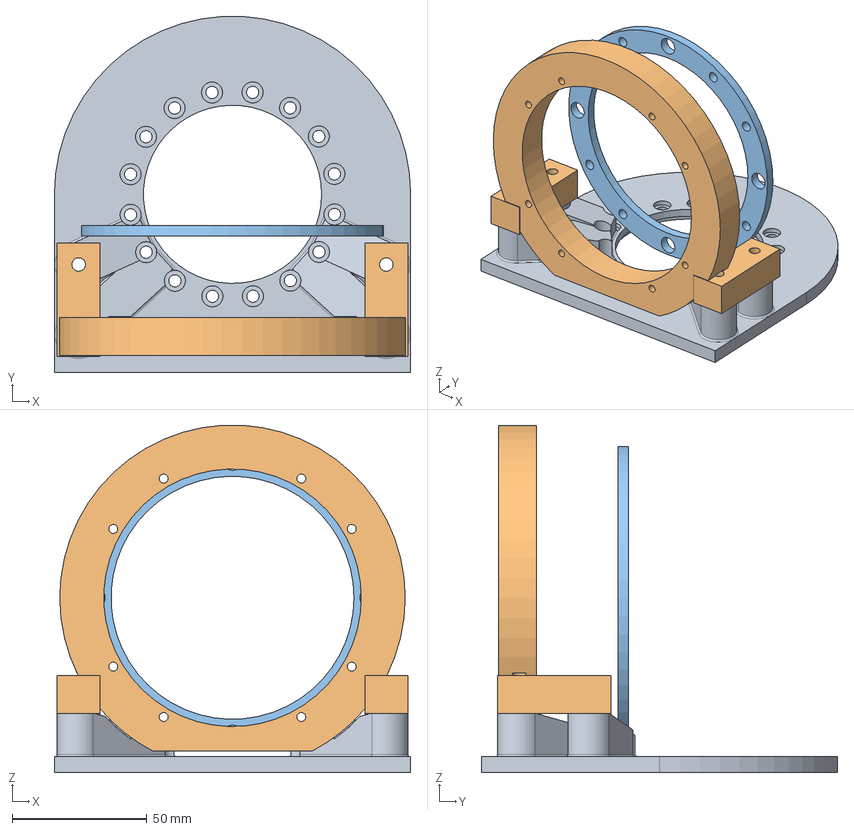
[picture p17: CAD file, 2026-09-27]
engineering/generated/link12-study/ODR-LINK12-original-assembly.step
132.0 x 131.9 x 128.7 mm

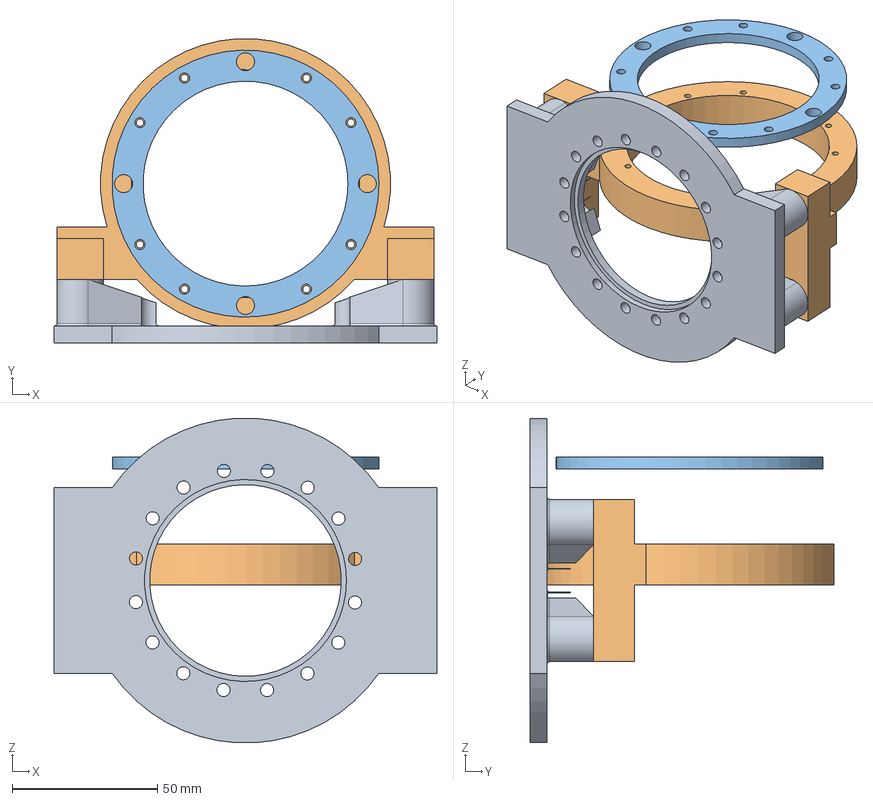
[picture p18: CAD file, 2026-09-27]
engineering/generated/link23-study/ODR-LINK23-original-assembly.step
132.0 x 104.9 x 111.8 mm

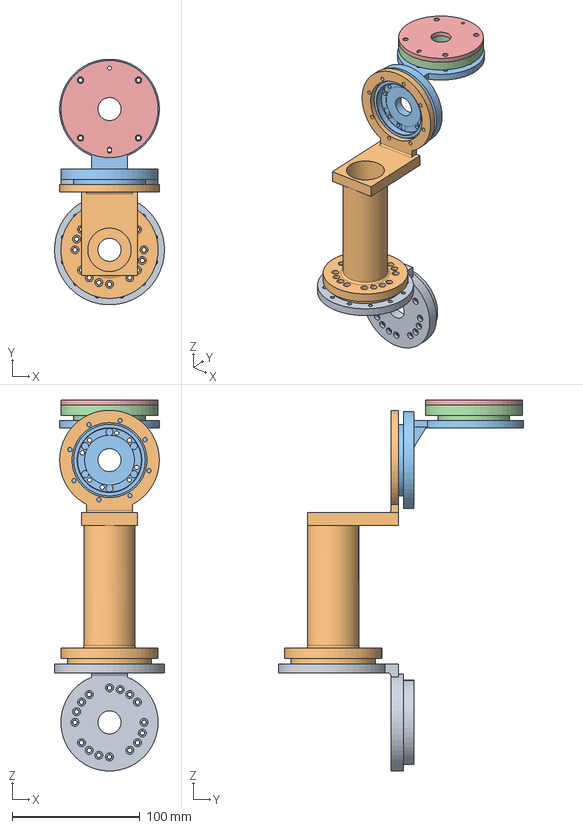
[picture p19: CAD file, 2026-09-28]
engineering/generated/r5-link45-erob01/STEP/ORIGINAL-context-assembly.step
86.0 x 191.8 x 290.0 mm
L45_E01
L56
W01
A01P
H01

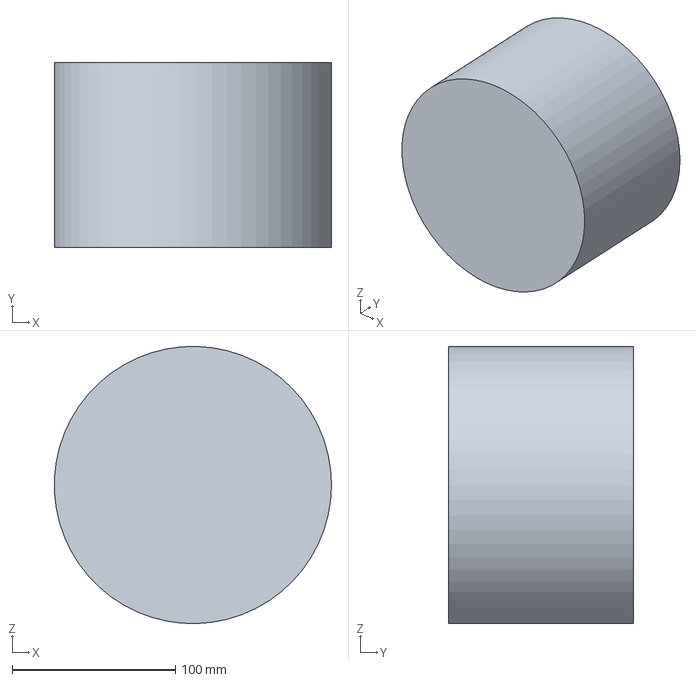
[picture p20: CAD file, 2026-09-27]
engineering/generated/shoulder-raise-01/full-rotation-envelope.step
169.9 x 113.5 x 169.9 mm

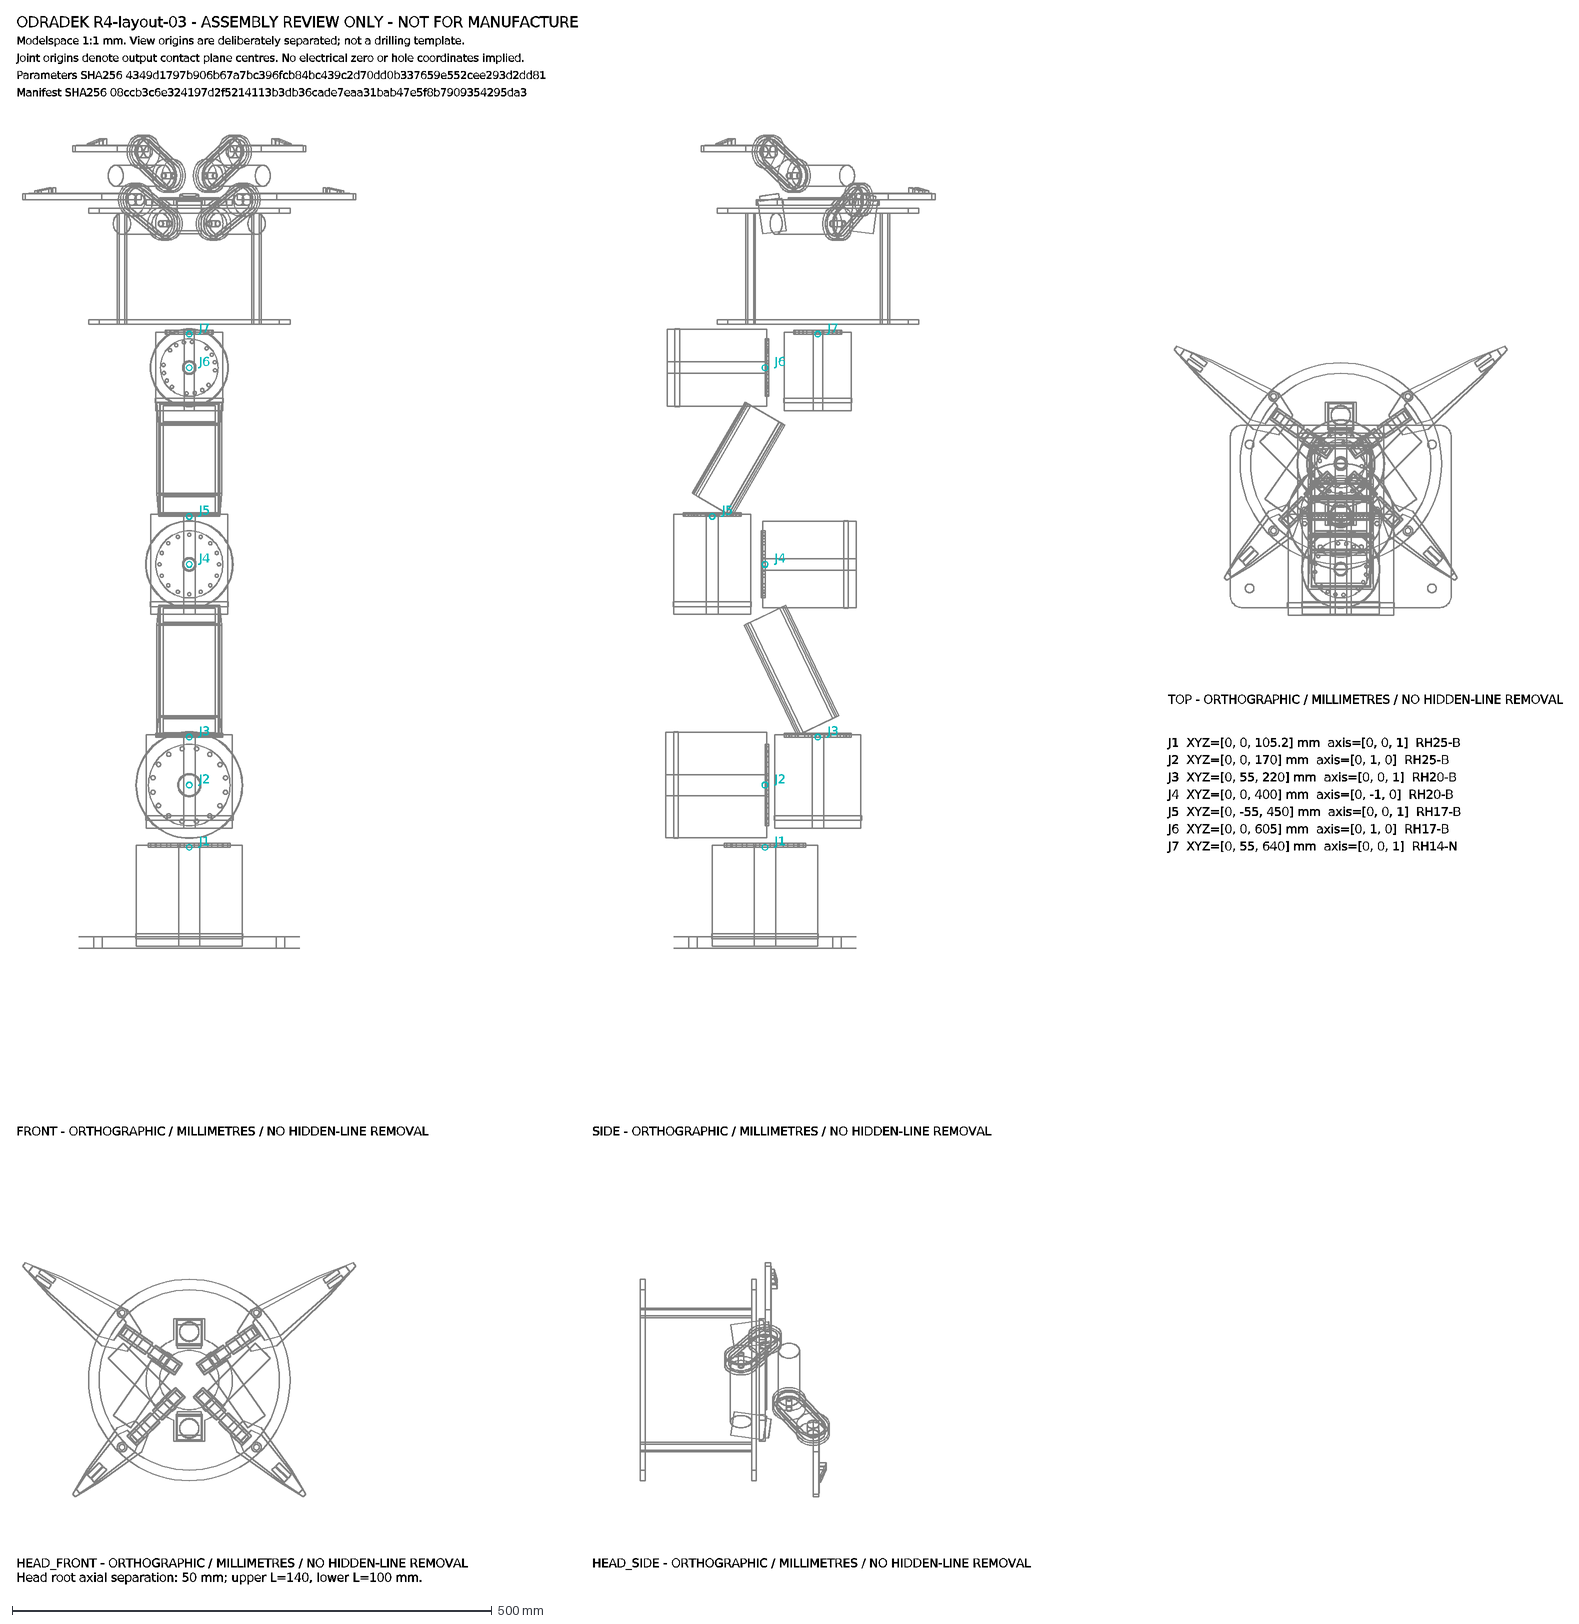
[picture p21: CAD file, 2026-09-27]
engineering/generated/layout/ODR-R4-assembly-review.dxf
FRONT - ORTHOGRAPHIC / MILLIMETRES / NO HIDDEN-LINE REMOVAL
SIDE - ORTHOGRAPHIC / MILLIMETRES / NO HIDDEN-LINE REMOVAL
TOP - ORTHOGRAPHIC / MILLIMETRES / NO HIDDEN-LINE REMOVAL
HEAD_FRONT - ORTHOGRAPHIC / MILLIMETRES / NO HIDDEN-LINE REMOVAL
HEAD_SIDE - ORTHOGRAPHIC / MILLIMETRES / NO HIDDEN-LINE REMOVAL
J1
J2
J3
J4
J5
J6
J7
ODRADEK R4-layout-03 - ASSEMBLY REVIEW ONLY - NOT FOR MANUFACTURE
Modelspace 1:1 mm. View origins are deliberately separated; not a drilling template.
Joint origins denote output contact plane centres. No electrical zero or hole coordinates implied.
Parameters SHA256 4349d1797b906b67a7bc396fcb84bc439c2d70dd0b337659e552cee293d2dd81
Manifest SHA256 08ccb3c6e324197d2f5214113b3db36cade7eaa31bab47e5f8b7909354295da3
J1 XYZ=[0, 0, 105.2] mm axis=[0, 0, 1] RH25-B
J2 XYZ=[0, 0, 170] mm axis=[0, 1, 0] RH25-B
J3 XYZ=[0, 55, 220] mm axis=[0, 0, 1] RH20-B
J4 XYZ=[0, 0, 400] mm axis=[0, -1, 0] RH20-B
J5 XYZ=[0, -55, 450] mm axis=[0, 0, 1] RH17-B
J6 XYZ=[0, 0, 605] mm axis=[0, 1, 0] RH17-B
J7 XYZ=[0, 55, 640] mm axis=[0, 0, 1] RH14-N
Head root axial separation: 50 mm; upper L=140, lower L=100 mm.

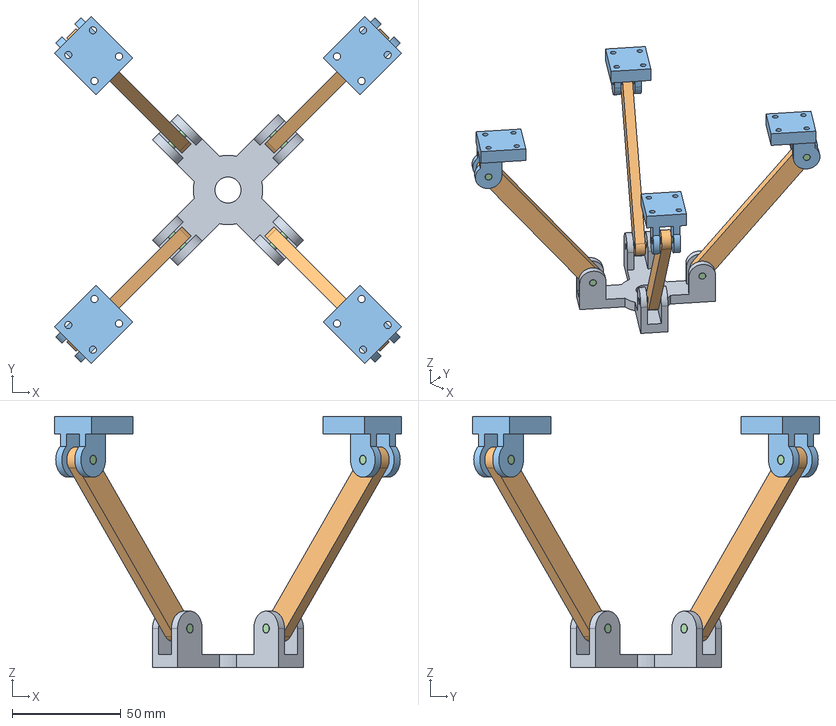
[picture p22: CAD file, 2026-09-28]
engineering/generated/r5-sync01/sync-subassembly-R66.step
159.8 x 159.8 x 115.7 mm
spider
UR_rod
UR_lug
UR_inner_pin
UR_outer_pin
UL_rod
UL_lug
UL_inner_pin
UL_outer_pin
LL_rod
LL_lug
LL_inner_pin
LL_outer_pin
LR_rod
LR_lug
LR_inner_pin
LR_outer_pin

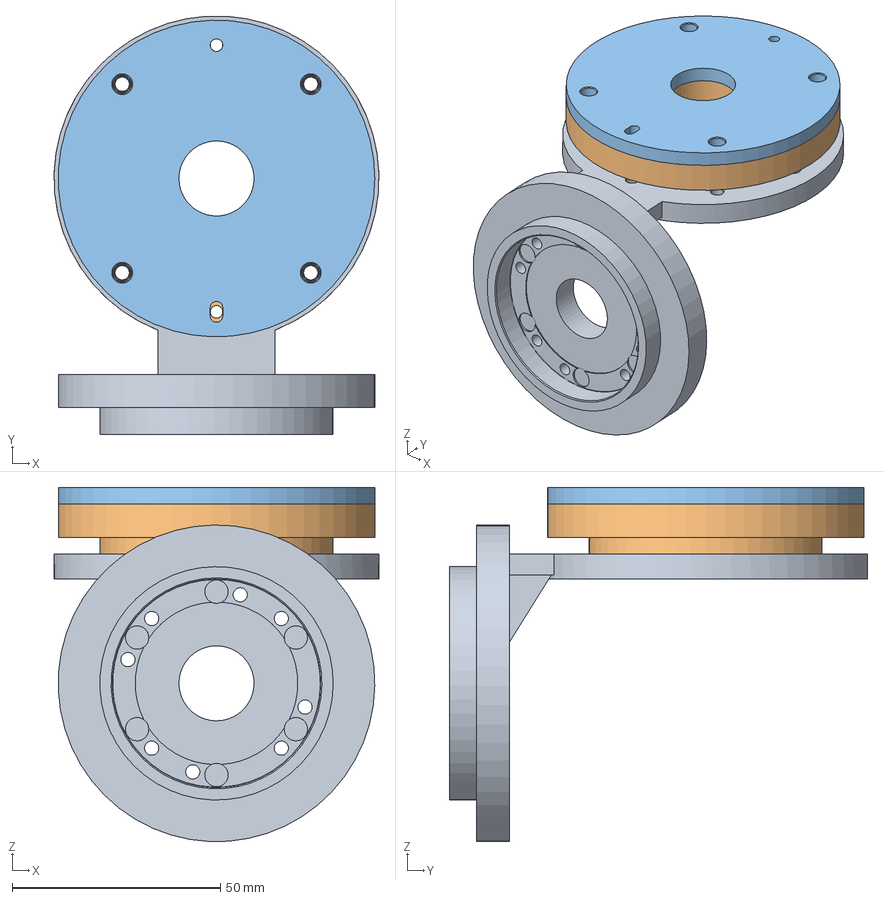
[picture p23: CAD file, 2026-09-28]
engineering/generated/r5-wrist-pair01/STEP/ORIGINAL-assembly.step
78.0 x 100.4 x 85.0 mm
W01
A01-P
H01

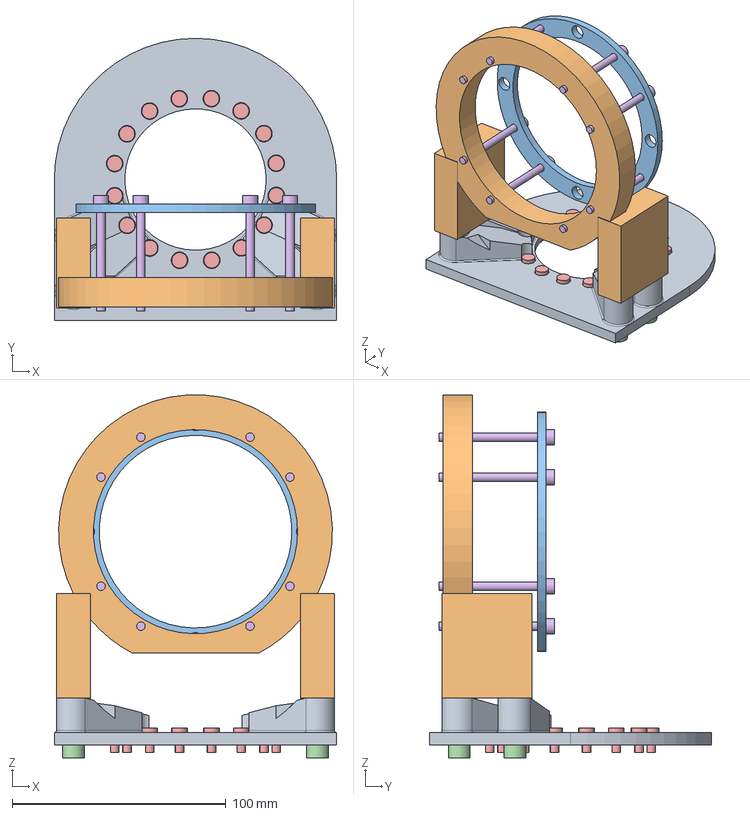
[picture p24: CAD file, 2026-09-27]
engineering/generated/shoulder-raise-01/SHOULDER-RAISE01-original-L12-assembly.step
132.0 x 132.0 x 169.7 mm
L12_output_adapter
L12_rear_fork
L12_front_ring
L12_HW_FOOT_M6x35_1
L12_HW_FOOT_M6x35_2
L12_HW_FOOT_M6x35_3
L12_HW_FOOT_M6x35_4
L12_HW_OUT_M4_unknown_1
L12_HW_OUT_M4_unknown_2
L12_HW_OUT_M4_unknown_3
L12_HW_OUT_M4_unknown_4
L12_HW_OUT_M4_unknown_5
L12_HW_OUT_M4_unknown_6
L12_HW_OUT_M4_unknown_7
L12_HW_OUT_M4_unknown_8
L12_HW_OUT_M4_unknown_9
L12_HW_OUT_M4_unknown_10
L12_HW_OUT_M4_unknown_11
L12_HW_OUT_M4_unknown_12
L12_HW_OUT_M4_unknown_13
L12_HW_OUT_M4_unknown_14
L12_HW_OUT_M4_unknown_15
L12_HW_OUT_M4_unknown_16
L12_HW_FIX_M4x50_1
L12_HW_FIX_M4x50_2
L12_HW_FIX_M4x50_3
L12_HW_FIX_M4x50_4
L12_HW_FIX_M4x50_5
L12_HW_FIX_M4x50_6
L12_HW_FIX_M4x50_7
L12_HW_FIX_M4x50_8

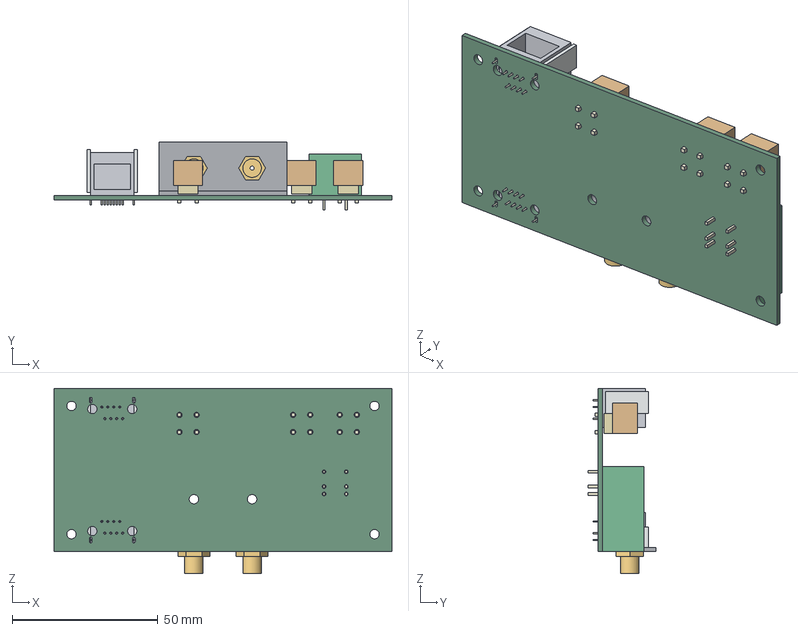
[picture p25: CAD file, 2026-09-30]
engineering/electronics/base-rear-interface01/mechanical/base-rear-interface01-assembly.step
116.0 x 23.4 x 63.5 mm
BRI01_PCB
J1_shell_reference
J1_spring_reservation_-8.65
J1_spring_reservation_7.5
J1_tail_0
J1_tail_1
J1_tail_2
J1_tail_3
J1_tail_4
J1_tail_5
J1_tail_6
J1_tail_7
J1_tail_8
J1_tail_9
J2_shell_reference
J2_spring_reservation_-8.65
J2_spring_reservation_7.5
J2_tail_0
J2_tail_1
J2_tail_2
J2_tail_3
J2_tail_4
J2_tail_5
J2_tail_6
J2_tail_7
J2_tail_8
J2_tail_9
J3_header_reference
J3_tail_0
J3_tail_1
J3_tail_2
J3_tail_3
J3_tail_4
J3_tail_5
J4_M3_stud
J4_lug_nut_reservation
J4_tail_0
J4_tail_1
J4_tail_2
J4_tail_3
J5_M3_stud
J5_lug_nut_reservation
J5_tail_0
J5_tail_1
J5_tail_2
J5_tail_3
J6_M3_stud
J6_lug_nut_reservation
J6_tail_0
J6_tail_1
J6_tail_2
J6_tail_3
BRI01_COAX_LEDGE
X1_132170_reference
X1_fixed_flange
X1_nut_washer_reservation
X2_132170_reference
X2_fixed_flange
X2_nut_washer_reservation

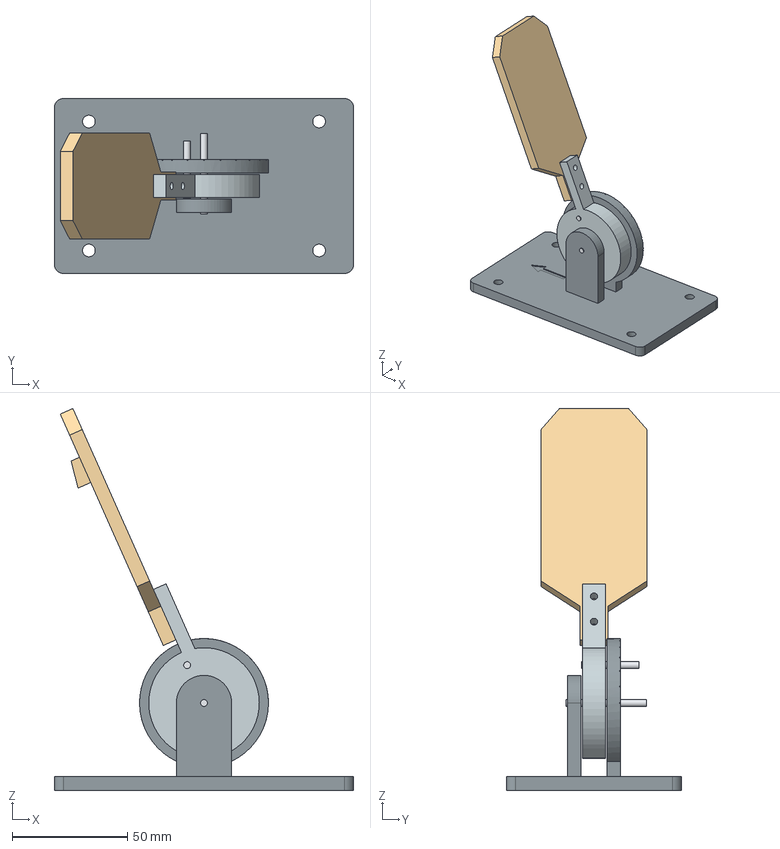
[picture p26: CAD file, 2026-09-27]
engineering/generated/finger-fixture/STEP/assembly-upper-q114p000.step
130.0 x 76.0 x 165.9 mm
base
rotor
upper
axis_reference_only
stop_pin_reference_only

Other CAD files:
engineering/base_b06/build/exterior/slice-review/B06-301-MAIN-SHIELD-review.3mf
engineering/generated/link45-study/ODR-LINK45-original-assembly.step
engineering/generated/p16-carrier-01/main-carrier.step
engineering/generated/r5-link56-erob01/STEP/ORIGINAL-context-assembly.step
engineering/base_b04/build/ODR-BASE-B04-P2.blend
engineering/base_b04/build/ODR-BASE-B04-P2.step
engineering/base_b04/build/checkpoints/P1/ODR-BASE-B04-P1.blend
engineering/base_b04/build/checkpoints/P1/ODR-BASE-B04-P1.step
engineering/base_b04/build/checkpoints/P1/unused-parts/HW-M3-COVER-BOTTOM-0.stl
engineering/base_b04/build/checkpoints/P1/unused-parts/HW-M3-COVER-BOTTOM-1.stl
engineering/base_b04/build/checkpoints/P1/unused-parts/HW-M3-COVER-BOTTOM-2.stl
engineering/base_b04/build/checkpoints/P1/unused-parts/HW-M3-COVER-BOTTOM-3.stl
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

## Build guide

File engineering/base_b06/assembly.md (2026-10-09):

<!-- SPDX-License-Identifier: CC-BY-NC-4.0 -->
# B06-COMPACT-07-DFM 无动力样件装配顺序

单位mm。Z0是桌面，+Y朝桌内，机械臂根轴位于(0,75)。仅适用于当前模型，禁止把历史B04/B05件混装。先核对BOM、图纸、模型及PCB版本；灯板、线束和插头释放仍是未关闭的整套放行项。

**默认独立底座：** 第2节的第3/4步属于可选机械臂集成，独立装配时跳过；在法兰M8和承力板装好后安装主罩，再从Ø136颈口放入OD134测试适配盘，以八颗M6×20/1.6垫圈固定。测试杆另用四颗M8×25/垫圈固定。工装、加载设备与配重不属于产品BOM。详见[独立验证](standalone-validation.md)及工装STEP/评审图。八颗机械臂/工装安装M6不计入默认底座承力架STEP。

## 1. 金属件与桌夹预装

1. 将B06-101/102/103按STEP位置组成B06-W01焊接件：上板下表面Z2、腹板顶Z2；腹板底Z−90、下夹板顶Z−90。四条连续140mm角焊缝，名义焊脚z5/喉厚3.54，最大5.5mm避让包络；模型包含四条名义焊缝实体。实际焊接强度、WPS、端部和变形控制由制造方评审；按[制造定义](manufacturing.md)核对实物焊趾与桌边，0.5mm名义间隙不是公差保证。
2. 焊后确认上板基准平面和上下夹板相对位置，复查M12/M6螺纹。不得让焊瘤进入桌面保护垫区域或螺孔。不要在已装PCB、塑料、硅胶附近焊接。
3. 各M12螺杆装采购DIN6311压脚与随件卡环；压脚Ø25平面朝上。分压板与硅胶垫放在压脚上方。压脚球面座和卡环必须用原厂实际件核对，现有模型只有保守尺寸包络。

## 2. 灯板、承力架、外罩与可选根座

1. 准备主罩，先从内部放入四个M3螺母。主罩倒置，在前灯两个内部槽从−Y方向放入DIN934 M2螺母(AF4/高1.6)，放灯窗，再将50×14×1.6灯板顶面朝灯窗，Ø2.4孔对准X±23/Y163.5。把压条两枚Ø2.7柱穿过板上Ø3.2 NPTH；两颗M2×8内六角从下方锁入隐藏螺母，板底Z44.073/板顶Z45.673。先核对未压伤板子、LED不接触灯窗；灯窗支撑间隙至少0.4mm，需要软垫试样确定厚度与压缩。GH线端先插入再装承力架，板上引脚1/2/3分别5V/PWM/GND，禁止接48V。
2. 在B06-104法兰下方安装四根B06-105柱，使用顶部M8×16。柱端面坐实，四个螺钉尖端Z33.5；柱底Z17。此步骤必须在根座覆盖法兰孔位之前完成。
3. 主罩颈口Ø136，小于根座外径Ø140；从主罩的大底部开口放入裸根座，不能从颈口硬压入。将法兰/柱组件从下方定位到根座下方，上配合面Z58。
4. 从裸根座上方依次装八个M6×20和1.6厚垫圈，PCD120、初相位22.5°。名义根座厚8、法兰螺纹咬合10.4。必须先装并检查这八颗螺钉，再装电机、顶部环和腰部外罩；模型中已用Ø13工具实体核对裸根座阶段的直线进入空间。
5. 从底部装金属承力板到四柱底端，再装底部M8×20。头部坐在Z10.5沉孔面，名义柱内咬合13.5，与上螺钉尖端间隔3。粘保护垫、夹桌和装盒架之前完成这些底向螺钉。
6. 外罩与根座是两条不同的定位/受力路径；不要用塑料隐藏M3螺钉代替根座M6或柱M8。

## 3. 接口板与后盖

1. B06-307底架放入四个PCB M3螺母和两个后盖M3螺母；PCB螺母从两侧插入，后盖螺母从上方放入。确认螺母不转动，必要时先做螺母配合小样。
2. 在PCB尚未装入底座时，用两个M3×8、上下0.5厚垫圈、M3螺母将空B06-309同轴支架固定到原生H5/H6，中心(X±10,Y−8)。PCB底面Z24，顶面25.6。确认板下螺母不接触铜皮；保持原生安装孔禁布区。支架螺钉必须在同轴接头安装前拧紧；接头本体会挡住上方工具进入，不能颠倒顺序。
3. 再将两个RF连接器装入支架：后侧AF9.8六角凹位容纳名义AF9.5固定法兰，前侧采购螺母锁紧。不得让装配扭矩传到板焊点或后盖；真实同轴插头/螺母扳手空间需样件检查。若日后拆支架，需先退出同轴连接器。
4. 用四个M3×10将PCB固定到底架，中心(X±52,Y−20/24)。原生板框116×56×1.6，不能缩放PCB/封装来适应开孔。
5. 四个主罩隐藏M3×10从底面装入；后盖两颗M3×10从背面装入，轴高Z32。后盖从后方接近，两个螺钉头落在凹入平座。
6. 接口对应关系：背部RJ45窗口是专用EtherCAT布线通路；两个同轴窗口直通外置GMSL接收设备；独立48V插头供电。接口板包含前灯支路F1/D1/就地5V及STM32灯控，不含EtherCAT主站/ESC、GMSL解码或整机48V协调保护。J8内部UART线接外置控制器，J9为断电检修后接入的SWD接口；接插件先于封盖插合并检查无挤线。
7. 断电检修时先拔全部外部插头，再退出两颗后盖螺钉，后移40后抬起。现有报告只检查13个位置，贴墙安装须另留维护空间；不可据此保证贴墙原位拆盖。

## 4. 桌夹与盒架

1. 只用于已确认的平整桌面15–60厚预算。不得用于玻璃、空心纸蜂窝或强度未确认桌面并据此声称带载安全；首件验证桌面局部压力和防滑后再定使用边界。
2. 先把已预装底座放到后沿，再将两套分压板/保护垫居中放在(X±45,Y50)。从下方用AF6六角扳手交替转动M12螺杆，使两侧接触并均衡收紧。
3. 结构筛查中的每杆1500N预紧仅是计算假设；K=0.2换算约3.6Nm不是可直接发给用户的锁紧扭矩。实际预紧、桌面损伤和防滑须在受约束测试台标定。
4. 两侧盒架通过四个M6×20和垫圈连到腹板侧面(Y−55,Z−80/−67)。它们可独立拆除，不用松开夹桌螺杆。
5. 托盘用四颗M4×10，头沉入Ø8.4×3沉孔且低于盒体底面；这四颗不要加垫圈。前后限位条各两颗M4×20。
6. 盒体预算180×150×50、3kg。用20宽粘扣带穿托盘两侧4×24槽，固定盒体；机箱通风口不应被垫/带盖住。取出盒子先松带、拆朝桌内的前限位条，再向+Y抽出；无须松桌夹。实际盒体通风和接插件仍待最终盒型确认。

## 首件必须记录

- 逐件尺寸/孔距、打印壁厚和螺母袋配合；实际螺钉不得顶底、压PCB或刮线。
- 焊接变形、平面度、螺纹通止及金属毛刺；桌夹压脚卡环正常。
- 外罩/后盖装配、灯窗压紧、RJ45锁扣/电源拔插/同轴扳手操作和线缆弯曲。
- 盒架3kg独立承重、盒子抽取；桌夹防滑/桌面压力的单独约束测试。
- 后续再做限流通电、保护、温升、EtherCAT和双GMSL链路；上述无动力检查不能替代运行放行。

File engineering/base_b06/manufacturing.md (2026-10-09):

<!-- SPDX-License-Identifier: CC-BY-NC-4.0 -->
# B06-COMPACT-07-DFM 制造定义与首件要求

本文件用于加工方报价、工艺评审和首件准备。外形、接口及独立验证范围沿用批准方案；**不是整套生产放行文件**。当前可以评估分件加工与板级打样，整套备料和带载运行须关闭下面的装配定义并取得实测结果。默认不需要机械臂。

## 资料与采购边界

- `build/B06-manufacturing-bom.csv`合并当前机械件、当前嘉立创IO六个元件和灯板十二个元件，以及明确列出的未关闭线束/光学/接地/工艺项。装配父项与元件子项分层：采购成品PCBA或采购裸板与散件装配，不能重复计算。
- `build/B06-first-article-traveler.csv`是19步首件检验流转表，实测值、仪器、操作人和证据为空；不预填合格。
- `build/manufacturing-definition.json`绑定原生BOM和本文件指纹；`qualification.py`把制造定义纳入版本指纹。19步首件记录不替代原有21项独立物理验证。
- 产品外罩仍为五件打印件。金属承力件和测试工装的STL用于几何评审，不能据此用塑料替代金属受力件。外置盒本体、机械臂和加载器不在产品BOM内。

## W01焊接装配

B06-101上板、102腹板、103下夹板构成同一个焊接件。四条连续角焊缝，每条名义140mm，名义焊脚z5、名义喉厚约3.54mm；为避让设置的最大焊脚包络5.5mm。这只是工艺评审候选，制造方需确认焊接强度、WPS、端部处理、应力/变形控制和检验等级。允许平/凹焊缝须仍位于约定包络；不能以增加凸焊肉填满桌后沿间隙。模型有四个名义焊缝实体；焊缝不是独立采购的零件。

前焊趾名义Y−46，最大尺寸包络Y−45.5；参考桌边Y−45，因此最大焊缝只剩**0.5mm名义间隙**。这不是安装公差保证：真实焊趾、桌边圆角、保护垫和定位误差都需首件实测。装夹前确保桌边未碰焊缝；有接触则停止装配，调整受控位置或返修焊件，不能靠收紧螺杆挤过干涉。现有检查覆盖15/30/60mm桌厚，未覆盖全部实际桌面形状。

焊后再加工关键座面并复查螺纹。候选上承力板平面度0.15mm是明确待测项目；涂层后的平面度也须记录。焊接与打磨不能在已装塑料、硅胶或电子件附近进行。

## 基准、公差和检验方式

承力焊件加工基准为上板上平面Z17；腹板后平面Y−59为装夹方向基准。成品接口使用法兰上平面Z58、中央Ø56轴线XY(0,75)及孔组初相位作为统一测量坐标。不要把外罩曲面作为承力孔组加工基准。

PCD120八M6、初相位22.5°、Ø160/Ø56法兰及四柱长度29mm按当前接口契约和STEP记录。坐标表是名义尺寸；当前没有对全体零件分配可放行的位置度/平行度公差，禁止把“坐标±0.1”自行解释成“径向位置度0.1”。供应方评审后需要给出各关键孔组的共同基准和明确公差，再签署加工图。模型交集判断0.01mm³不是制造公差。

盲孔应分别检查钻孔深度与完整螺纹深度；螺纹采用通止规。四柱顶底螺钉之间名义3mm间隔需用实际螺钉、座面和孔深核对，不能只量总柱长。金属加工去毛刺并避免线束路径上的尖边；涂层遮蔽螺纹、接地接触面和定位座面，实际防腐工艺待供应方确认。

## IO板接线柱与装配工艺阻断项

J4/J5/J6为[Würth74651173](https://www.we-online.com/components/products/datasheet/74651173.pdf)：M3螺纹高3±0.2mm，接线柱给出的紧固扭矩0.5Nm；厂家明确波峰焊不适用、推荐回流。全板存在多种连接器，制造方必须给出兼容的混合装配流程，不能默认全板波峰焊。

候选[TE165295 M3接线环](https://www.te.com/en/product-165295.html)板厚0.79mm。配普通M3螺母名义2.4mm，叠层3.19mm已超过名义3mm螺纹，因此不接受“占位包络放得下即装配合格”。当前备选ISO4035 M3薄螺母名义1.8mm、不另加垫圈，名义叠层2.59mm，与最短2.8mm螺纹只差0.21mm；接线环/螺母公差、有效首牙、锁紧保持和抗转动仍待真实件核对。**此候选未放行，不能先下单全套线束。** 若样件不能满足有效咬合与保持，需要更换接线柱或连接方式，并同步原生PCB、MCAD、BOM和检验文件。

J6是机壳接地边界，不等同于J5电源返回。金属上板有专用M6接地点，但接线环、螺钉长度/接触齿垫、表面遮蔽、导体截面和实际工具空间未关闭。不得用未确认的接线柱额定电流替代PCB铜箔、压接线束和整机温升资格。

## 线束与灯窗

所有线束要形成两端定义、线色、截面、实测长度、压接工具、夹持位置、最小弯曲半径和检验方法的单独图纸。当前BOM明确列出五类线束，而不是宣称它们已选型完成。背部端口不会自动成为普通PC网口：RJ45保持专用EtherCAT边界，双同轴GMSL接外部接收设备。不能接48V到RJ45或灯板。

灯板GH三芯顺序1=5V、2=PWM、3=GND；底座IO J7同顺序。48V由底座板的F1、D1、U1就地产生5V，再经内部短线接灯板。J7.2现接STM32灯控候选；固件编译和软件测试通过不代表实板灯效已验证，被动EtherCAT直通口不产生PWM。不增加外置5V线。光学软垫压缩、透光及耐温需实测。

### 就地5V电源打样候选

同一个原生立创工程已加入7个元件：RECOM R-78HB5.0-0.5、Littelfuse0451.500MRL、DiodesS1B-13-F、TDKC5750X7S2A106K230KB、YageoCC0805KKX7R9BB105/RC0805FR-07470RL、JSTBM03B-GHS-TBT(LF)(SN)。见[当前原生制造导出](../electronics/base-io-b05/manufacturing/b06-io-control01/)及[就地电源说明](../electronics/base-io-b05/local5v/README.md)。旧b06-io-prototype导出只供历史对照。

超过50V输入的有效电容必须满足厂家3.3µF/100V要求。所选10µF/100V X7S电容仍需核对52.8V直流偏压、负容差、温度及老化后的最低有效电容，不可只用标称10µF认定满足。F1用于输入支路，D1用于反接隔离；均未证明热插拔浪涌、反接、输出故障及熔断配合。首轮以5V输出100mA限流预算进行板级测试，不能继承模块500mA额定能力为整板能力。

厂家建议最小10mA负载。灯关闭时不能假定LED维持这个负载，候选470Ω/1%/至少0.125W泄放电阻在4.75V最低输出下约10.01mA，5.25V最高输出下功耗约59.3mW；后续若常开控制电路已满足负载可取消，须重新核算。输出允许范围、启动、纹波、EMI和温升在实际低负载下实测；模块额定值不是整板放行。

同一原生IO板已增加13个控制器元件和UART/SWD接口，详见[CONTROL-01](../electronics/base-io-b05/controller/README.md)。当前32个原生器件含6个安装孔、26个实际元件；旧13元件Gerber为历史导出。现已重建铺铜、保存复开，严格DRC为0；当前26元件Gerber/BOM/坐标/IPC356保存在 `b06-io-control01`，源指纹与原生板绑定。物理板级验证及整机放行仍未完成。UART线经隐藏接线仓，供电不另走桌下。

## 放行顺序

先关闭端子叠层、连接器真实配合、线束和关键公差，再签无动力完整打样资料；首件按流转表装配、测量和留证。随后按独立测试计划验证桌夹/盒架、接地/温升/保护、EtherCAT与双GMSL、灯效。加载前先资格确认独立金属工装及加载器。当前物理通过0/21；任何数字检查、文件完整性或报价都不能把生产状态改为已放行。

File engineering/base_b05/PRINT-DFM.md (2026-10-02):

<!-- SPDX-License-Identifier: CC-BY-NC-4.0 -->
# B05 打印与装配检查边界

本文件是给 B05 建模使用的分件建议及网格检查说明。实际零件名称、尺寸和紧固件以 B05 最终模型及 BOM 为准；它不声明 B05 已通过实物装配或承载试验。

## B04 暴露出的具体问题

当前 B04 manifest 中前罩约 270.15×210.66×51 mm、后罩约 259.99×94.61×51 mm。它们不是一般 220 mm 方形打印床上可以直接平放打印的零件。STL 封闭并不等于打印机能够容纳，也不证明打印孔位和接头可以实配。

B04 接口面向下。最新参考要求后部内凹接口面板，外面另有后盖，接线后通过下方出口向桌下引线。这需要一起重排接口插头、锁扣/扳手操作、线缆转弯和后盖空间，不能只改变外壳外形。

## 给外观与结构建模的分件建议

- 环台独立。中央环台围绕金属承力接口，外观件与承力法兰留装配间隙，不用外罩传递机械臂载荷。
- 宽肩按左/右、前/后分区。B04 全壳跨越约 270 mm 宽、310 mm 深；仅左右分半仍可能超出打印床。以四个肩甲分区为起点，每件在选定打印姿态下控制到约 210×210×250 mm 内，再把分缝沿装甲转折安排。前方灯模块可作为单独短饰件连接左右前肩，避免将灯窗切成两半。
- 外罩从上方分件拆装，使用短直定位止口，不做互相锁死的长燕尾。初轮止口每个配合面预留约 0.3 mm 作为试片起点；这不是经过设备验证的打印公差。公母试片验证后再冻结。
- 采用可见或可到达的螺钉、独立垫圈/垫肩及可更换嵌件。螺钉拉紧在局部实心支柱，不挤压薄肩面。嵌件安装方向、烙铁空间、螺钉长度和底部余量必须在三维中看得到。
- 光学件单独打印/制作。灯板、灯罩、遮光隔板和接插件能随前灯模块取出；在拔插灯线前，前罩应有可托住的开盖位置。透光件与外罩可用不同材料，但不因使用透明料而声称亮度或均匀性达标。
- 后部采用“内部承托架＋可更换接口面板＋后盖”。板和面板从支架上独立更换；面板约束插接方向，插拔力由支架承担。PCB 焊脚不作为承力定位，外观肩甲不承担电缆拉力。
- 后盖向后或向上直接取下。出线口应是开边槽加分体护线块，使接头不必穿过狭小孔洞才能拆盖。接线后外盖能闭合，且不会压住 RJ45 锁扣、同轴螺母、动力插头锁扣或线缆应力释放段。

后部面板必须依据实际选定连接器建立至少五个包络：板上本体、外露口、已插接插头、解锁工具/手指、线缆允许弯曲区。不同接口不能共用一个“圆孔占位”；同轴接口额外保留装配扳手空间。线缆最小弯曲半径按具体线缆数据和实配确定，不用通用弧线替代。

## 首件文件如何交付

Blender 文件用于外观编辑、装配观察和渲染。切片输入使用**逐个零件的 STL 或 3MF**，单位为 mm；不要用总装 GLB，也不要让购买件、螺钉、PCB 或线缆检具混入打印件文件夹。

建议目录分开：

```text
build/print-parts/       # 外罩、灯罩、面板、后盖等真正试打印件
build/assembly-mockups/  # 如需打印的金属结构占位检具，醒目标注“无动力装配”
build/reports/           # 绑定本次输出散列的检查结果
```

每个零件同时给出装配姿态和打印姿态，明确打印材料、层高、壁数、支撑面、孔后加工、嵌件安装及采购紧固件。打印姿态下的放置只是第一步，仍需在实际切片器中逐层查看薄壁、悬空、支撑接触面和孔是否闭合。未知打印机时，220×220×250 mm 仅作为本项目暂用兼容检查床，不代表用户设备。

承力金属底板、桌夹、法兰和托架可以打印占位件检查拆装顺序，但应放在 `assembly-mockups/`。这些占位件不得用于给机械臂施加载荷、夹紧力或证明 2 kg 工件能力。

## 使用网格检查器

依赖 Python 3、`numpy`、`trimesh`。在仓库根目录运行：

```sh
python engineering/base_b05/print_checks.py \
  engineering/base_b05/build/print-parts \
  --bed 220 220 250 --margin 5 \
  --output engineering/base_b05/build/reports/print-checks.json

python engineering/base_b05/print_checks.py --self-test
```

默认给打印床 X/Y 每边留 5 mm，因此当前打印姿态可用范围为 210×210×250 mm。包络检查允许把整体平移到打印床，但不会静默旋转零件。STL 本身没有单位，默认明确按 mm 解读；米制 STL 必须传 `--stl-unit m`。

`--allow-orthogonal-rotation` 仅用于筛查“换一个坐标轴朝上是否装得下”。默认不开启，避免把侧立才能放下的罩壳标成已完成打印准备。即使开启，报告仍保留导出姿态是否适配，且不把所有可容纳的姿态当作合理打印姿态。

检查器会记录输入及脚本 SHA-256、库版本、封闭性、面绕向、按共享边连接的壳数量、退化/重复三角面、带符号体积、尺寸和包络；仅合并重合顶点来读取 STL 拓扑，不自动补孔或修复错误。默认要求每个打印对象只有一个封闭连通壳。双壁完全密闭的中空模型可能因具有独立内外壳而被拒绝，需要人工确认并更改模型/验收要求，不能删除内壁使检查通过。

Core 3MF 保留内嵌单位、组件实例和变换；必需扩展、跨文件组件等本检查器不支持的内容会报错。多对象 3MF 按每个实例检查，并另外报告整组包络；**不检查不同对象之间是否重叠**，必须重新切片排板。多个 STL 也按单件检查，不意味着可以同一盘全部打印。

返回值 0 只表示所检查的网格及单件打印包络通过。非零表示至少一项不通过或文件不可读。网格自交、最小壁厚、支撑、层间强度、装配干涉、电气性能和承载均不在该脚本的通过结论内。

## 首件装配核对

1. 空底座先装金属骨架与后部支架；检查各螺钉和工具路径，再装 PCB。
2. 装好真实接口及线缆，确认面板位置与接头吻合、接线方向正确，能够解锁拔出。
3. 预装后盖，验证四路外线可自然向下离开，盖体不把压力施加在接头与线缆转弯处。
4. 分别装中央环台、肩甲和前灯模块；验证不用弯曲罩壳强行对孔，所有螺钉都能放入和取出。
5. 做完整无动力拆装一次，记录打印收缩、孔补偿、止口间隙和嵌件异常后修正文件。

仅在这些实配问题关闭后，才把外罩与接口模块标为“首件装配通过”；这与桌夹、承力结构、PCB 供电和通信的独立试验是不同结论。

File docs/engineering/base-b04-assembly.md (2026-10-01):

<!-- SPDX-License-Identifier: CC-BY-NC-4.0 -->
# B04 底座：三维装配与加工审查

> 当前入口：[B04-P2 三维审查包](../../engineering/base_b04/README.md)。P2 已加入飞碟盾形曲面、底座灯和独立后接口仓。下文 P1 骨架检查仅保留历史依据；数值以 P2 包绑定的记录为准。

本轮主交付是可拆分的三维装配与零件实体；PDF 和坐标表用于辅助核对加工特征。B04 是新底座原型，不继承早期 R4 穿桌锚固底座的尺寸或承载结论。实际采购件适配、制造和实物验证状态以本轮审查记录为准。

## 同一套三维数据

- [参数源](../../engineering/base_b04/parameters.json)定义 X 左右、+Y 向桌内、+Z 向上，桌面为 Z=0、后桌边为 Y=0。
- [实体源](../../engineering/base_b04/model.py)建立真实孔、沉孔、螺纹底孔、槽、间隙及分件；每个零件保留全局装配坐标。螺纹不建螺旋牙型，攻牙要求由特征表定义。
- [装配清单](../../engineering/base_b04/build/manifest.json)给出实体路径、材料、工艺和特征；加工必须同时读取对应 STEP 与该版清单。
- [三维装配 STEP](../../engineering/base_b04/build/ODR-BASE-B04-P2.step)保留零件装配关系；[GLB 预览模型](../../engineering/base_b04/build/ODR-BASE-B04-P2.glb)用于交互查看。GLB 是显示网格，制造尺寸以 STEP 与特征表为准。
- [辅助图册](../../engineering/base_b04/build/drawings/base-b04-manufacturing-review.pdf)和[特征坐标表](../../engineering/base_b04/build/drawings/feature-coordinates.csv)暂存为较早 P1 机械骨架检查点。它们基于清单散列 `ad065c979d159c1636a3b4f45636eb2d2e782b9553024c0c5ffa4498b730d9ef`，**不对应当前三维装配，不能配合当前 STEP 用于加工**。详情见[检查点说明](../../engineering/base_b04/build/drawings/README.md)。新版外罩、底座灯与接口开孔协同完成后再重生图册。
- [服务板接口合同](../../engineering/electronics/base-b04/connector-contract.json)规定 PCB 坐标、插头包络与拔出方向。电气板不承担整臂动力分配或机械载荷。

采购螺柱、压脚和控制盒占位若标为 `hardware`／`envelope`，只是有明确范围的装配表示；不能据此加工替代件，或声称已经核对全部供应商实物。

## 承力与拆分边界

臂根试验法兰经四根金属支柱传到底板；底板连接左右钢制 C 板、下横梁和两套桌夹螺杆。上下软垫把夹紧压力传给桌面。外观罩壳、足部保持罩及 PCB 支柱不进入机械臂主承力路径。臂根法兰是本项目的试验接口，尚不代表某个商业关节可以直接安装。

桌下托架连接 C 板固定部分，不连接调节螺杆或可动压脚。托盘、限位条和束带共同约束外置盒；控制盒可按 +Y 方向取出，其质量和空间分配不等于已选控制器。

## 装配顺序与可接近性

1. **先做金属件检查。** 核对材料与工艺、孔径／螺距、有效牙长、接触平面和去毛刺。用同版全局坐标检查配对孔，不把螺纹底孔直径当成成品内螺纹尺寸。
2. **桌外预装主骨架。** 在底板下表面可接近时安装四根法兰支柱和罩壳支柱，检查底部螺钉头不突出软垫支撑面。随后从两侧装 C 板及下横梁；侧向紧固需要工具直线进入，不能被外壳遮住后才装。
3. **装法兰与桌夹。** 固定上法兰；按供应商方式组合 M12 调节螺杆和摆动压脚，再安装扩压板、下软垫及非承力保持罩。保持罩耳沿 Y 方向布置，M3 孔位为 X=±85、Y=32／78 mm，避让两侧 C 板。压脚应直接抵金属扩压板，保持罩仅防脱，不替代压脚承压。
4. **装桌下托架。** 固定两侧托架和托盘，安装后止挡，保留前止挡可拆；完成线束和束带路径后再放入控制盒。托架拆装不应要求先松开主桌夹。
5. **安装服务板。** 固定 PCB 螺柱和电路板，核查板底焊脚、螺钉及金属底板之间的距离。J1/J2 按合同向 -X 拔出，J3 向 +X 拔出；须同时留插头、手指／工具、线缆出线和应变释放空间。
6. **先试线束，再盖罩。** 完成机壳连接点、后部下行线束固定及与夹紧面的避让；确认后罩可以向上拆除。罩壳不应把插头或线束压紧来获得外形闭合。
7. **桌上空载试装。** 分别核对候选桌厚时螺杆的有效啮合、下压脚姿态、上软垫接触和工具操作空间。具体夹紧力与紧固扭矩需有计算及硬件依据，不能以“拧紧”为可重复的载荷验收条件。

## 加工与装配审查重点

| 项目 | 应核对的具体内容 |
|---|---|
| 公差 | 参数中的机加工、打印、孔位置和平面度是本原型声明；孔位置公差仍须对应明确基准和检验方法。不得自行套入未指定的通用公差标准 |
| 底板支柱连接 | M8 底部沉孔需按实际剩余腹板校核局部承压与拉穿；不能只用底板外形总厚度计算 |
| 螺钉长度 | 以板厚、垫圈、座面与螺钉公差计算有效啮合、端部间隙和突出量；钻孔深度不等于有效螺纹啮合 |
| 打印件紧固孔 | 通用打印偏差不能保证小间隙 M3 孔直接装配；按最终工艺说明实施后钻或其他已定义修整，并检查实际孔位 |
| 采购压脚 | 外包直径和高度只覆盖空间分配；颈部、卡接方式、摆角及装入路径须对照到货件或完整供应商图 |
| 盒体维护 | 占位模型尺寸必须严格对应参数；前止挡拆卸、束带释放与 +Y 抽出过程须完整检查，不以缩小占位消除碰撞 |
| PCB 与线束 | 使用本版 KiCad 板及配套元件包络；裸板不碰撞不足以证明插头可拔、焊脚净空或线缆弯曲空间成立 |

本文件不把名义几何不相交、计算通过、PCB ERC／DRC 通过或图册清晰等同于制造放行。未关闭项必须保留在交付说明中；后续修改应共同更新三维实体、特征表、质量、装配记录及对应电路板版本。

## 已完成的局部刚体复核

[独立 BREP 检查记录](../../engineering/base_b04/build/drawings/assembly-dfm-check.json)针对模型散列 `153bb04a9884f9586b6a2922c3e3215ae0b544a0c122ac2364cf1312bc035cc0`，在 15／30／60 mm 三种桌厚下检查了 90 对实体：下横梁 M8 头及垫圈与盒架耳板、保持罩及其 M3 螺钉与下横梁／C 板／盒架、压脚与下横梁。没有超过 0.001 mm³ 的交集；耳板的 D20 开边避让给 M8 头及垫圈留下 2 mm 名义距离，60 mm 桌厚时压脚和 M3 头到下横梁为 7 mm。

这份结果只描述指定源版本与所列刚体对的名义几何，未覆盖装入轨迹、公差、工具空间、实际压脚摆动、桌板接触压力或承载。模型后续更改须重新复核；它与上述较早 PDF 检查点是两份独立证据。

## 辅助图册复现

在具备 CadQuery、NumPy、ReportLab 和 pypdf 的项目 Python 环境运行：

```sh
python engineering/base_b04/drawings.py \
  --manifest engineering/base_b04/build/manifest.json \
  --font /path/to/Chinese-font.ttf
```

默认输出紧凑总装和成组特征表；需要逐件四视图时增加 `--individual-parts`。每次实体或清单更新后重新生成，并渲染 PDF 检查中文、表格和页边界。图册证据记录输入文件散列，避免把旧图配到新模型。

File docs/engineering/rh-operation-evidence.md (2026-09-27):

<!-- SPDX-License-Identifier: CC-BY-NC-4.0 -->
<!-- Required Notice: Odradek — Auromix contributors (https://github.com/Auromix/odradek) -->
# RH 运行、保持与接口证据复核

**RH-OPERATION-EVIDENCE-01 · 2026-09-27 · 原厂公开资料审查，未作采购、带载运行或停止功能放行。** 本次不改变关节选型、肩部结构、主参数或已冻结 CAD；补充 [候选表](hardware/joint-candidates.md) 的运行条件与接口缺口。机器记录见 [rh-operation-evidence.json](sources/rh-operation-evidence.json)。

可以确认：四个精确候选均有 48 V 标称、20–55 V 范围；B 版集成保持闸，由模块 DC 口供电；官网已有可下载的 ESI。仍不能确认：**各轴零速持续保持额定、保证的输出侧制动力矩、抱闸动作时序、实机固件与 ESI 一致性、有效螺纹起止及允许深入量**。这些缺口直接影响电源、失电保持和紧固件放行。

全部 PDF 页号从文件第一页计数。原厂 PDF、STEP、XML 和 SDK 留在本地研究目录；本仓库仅保存摘要、来源、哈希与独立测量，不重新分发原文件。没有外联询问、采购、下载后执行 SDK 或向硬件发送指令。

## 1. 精确型号与额定的适用范围

| 轴 | 精确订货候选，100:1 | 运行额定 / 目录峰值 N·m | 额定 / 峰值电流 A rms | 电机制动选项 | 零速连续输出保持 |
|---|---|---:|---:|---|---|
| J1、J2 | EPS-RH-25-100-E-B-D | 108 / 157 | 10.6 / 14.1 | B，带闸 | 未找到公开定额 |
| J3、J4 | EPS-RH-20-100-E-B-D | 50 / 80 | 6.8 / 10.6 | B，带闸 | 未找到公开定额 |
| J5、J6 | EPS-RH-17-100-E-B-D | 35 / 54 | 4.7 / 7.4 | B，带闸 | 未找到公开定额 |
| J7 | EPS-RH-14-100-E-N-D | 11 / 28 | 2.8 / 5.7 | N，**无闸** | 未找到公开定额 |

型号、B/N 选项与电气数据以各型号 `product manual 260805.pdf` PDF p1 为准，并与实时产品页交叉核对：[RH25](https://www.myactuator.com/rh-25details)、[RH20](https://www.myactuator.com/rh-20details)、[RH17](https://www.myactuator.com/rh-17details)、[RH14](https://www.myactuator.com/rh-14details)。`E` 明确为 EtherCAT / CAN BUS，`D` 为双编码器。旧 CAD 文件名省略 `EPS-`，不是新的订货代码。

四者额定转速均为 25 rpm；脚注明确额定测试在 **24°C 环境、无其他散热措施、额定转速、温升 60°C 达到热平衡**。它证明的是该测试条件下的运行额定，不能改写为 0 rpm 持续保持；温升测点、起始温度、安装散热边界和全封闭打印壳内降额尚不完整。用户手册 PDF p8 的环境 0–50°C 也不是整个温区恒扭矩保证。[原厂共享资料包](https://www.myactuator.com/_files/archives/cab28a_be98b58973d34f7aaa50bdf3f2aa12ed.zip)

同页另有 5–15 s 短时堵转数据；完整数值已在 JSON 按列人工视检记录。例如 RH25 的 162 / 216 / 256 N·m 对应 15 / 10 / 5 s、18 / 22.1 / 24.6 Arms，超过同页 157 N·m / 14.1 Arms 的目录峰值。RH17、RH20 也存在类似超出。两表的允许值、试验值及限流定义需澄清；**短时测量既不能替换较低目录峰值，也不能拼接成连续保持或重复工作循环**。RH14 的堵转电流亦可超过其目录峰值电流。

## 2. 抱闸与供电：已确认到模块接口层

用户手册 V1.4 PDF p27 §7.1 明确保持闸由模块自身 DC 连接器供电，无需另一路外部供电。因此本候选不新增“关节抱闸专用外供 24 V”。这不代表内部线圈就是 48 V，也不代表线圈电流、起动/保持 PWM、释放/接合时间已经公开。[用户手册下载入口](https://www.myactuator.com/downloads-rhseries)

| 型号 | 手册表 7-1 静态制动力矩 N·m | 可用结论 |
|---|---:|---|
| RH25 B | 1.2 | 表内未明电机侧/输出侧，不能乘 100 得到保证输出保持 |
| RH20 B | 0.8 | 同上 |
| RH17 B | 0.5 | 同上 |
| RH14 N | 通用 RH14 行为 0.2 | **对当前 N 版不适用**；不能补成 J7 抱闸能力 |

手册 PDF pp27–28 定义其为静态保持闸，并限制高载、高速动态制动；其寿命次数没有配套载荷、速度、能量或磨损后最小保持条件，不能作为整机急停验收依据。尚缺失电自然接合时间、欠压下动作、释放前建立转矩条件、故障时顺序、机械到位反馈及允许停止能量。J7 N 版失电后不能靠减速器摩擦或软件位置环保持姿态。

## 3. 电源、端口和针脚证据

共同电源是 48 V DC，产品允许范围 20–55 V；手册 PDF p24 警告超过 55 V 可损坏驱动。产品脚注还限制高于标称电压时不超过额定转速。实际电源调节误差、制动回馈、开关过冲必须共同落在边界内。

| 项目 | RH14 N | RH17 B / RH20 B | RH25 B |
|---|---|---|---|
| 原厂电源附件称谓 | XT30(2+2) | XT30(2+2) | XT30U-F |
| 随附电源线 | 18 AWG，200 mm | 18 AWG，200 mm | 14 AWG，200 mm |
| EtherCAT IN / OUT | SH1.0 mm 4 pin，附件线 480 mm | 同左 | 同左 |
| CAN / 多圈电池附件 | GH1.25-2P | 同左 | 同左 |
| BAT± | 有，多圈记忆电池用途 | 有 | 有 |
| RES± 泄放口 | **无** | 有 | 有 |
| 外部独立抱闸控制/供电针 | 无公开端口定义 | 无公开端口定义 | 无公开端口定义 |

以上来自四份产品册 PDF p2 及用户手册 PDF p25。`SH1.0` / `GH1.25` 是原厂目录称谓，未获得连接器制造商完整料号、镀层、锁扣和压接端子受控图。接口图给出 DC±、CAN_H/L、BAT±、RES± 与 EtherCAT T+/T−/R+/R−；图中左右排列已保存，但图示编号只是引出标号，**不直接等同于连接器 pin 1–4 或线侧视图**。制作线束前仍需实机标签、键位和对插面受控图。RES 是泄放电阻接口，BAT 是多圈记忆电池口，均不得接成抱闸外供电。EtherCAT 屏蔽双绞要求在手册 PDF p27。

额定/峰值 A rms 是电机电流资料，短时表明确为相电流，不能相加为 DC 母线电流。公开资料没有给出七轴同时运行 DC 需求、启动/抱闸瞬态、最低泄放电阻、斩波器连续/峰值电流与能量、开启阈值和滞回。手册 PDF p24 的 **1000 µF / 100 V** 只是开关上电过冲参考；pp29–30 的电阻、电容、电池是原理方案，不能代替本臂再生能量和器件定额计算。RH14 无 RES 口，必须在公共母线层解决其回馈；不能认为其供电模块天然吸收回馈。

Setup Software 截图可见过/欠压、堵转时间和抱闸 duty 配置项，但空白截图不提供出厂数值或写入许可。当前 [电气候选表](hardware/electrical-camera-candidates.md) 的 RSP-1000-48 仍是容量候选，未由此次审查获得停止能量或同时率验证。

## 4. EtherCAT：公开 ESI 已取得，实机适配仍待核

本次新增确认了 [英文 ESI 下载页](https://www.myactuator.com/downloads-ethercatesi) 与 [中文协议下载页](https://www.myactuator.cn/downlaodrj)：`MT-Device_260424.xml` 对应网页所列固件 `26042402`。英文、中文 ZIP 字节相同；XML SHA-256 为 `e102e7cbbff93480f7d2e5008b3031b034107f3ce2dead9349d80d48bacf2362`。XML 可解析，含 79 对象、CoE/PDO 配置与 FoE 描述，尚未做 XSD、EtherCAT 主站或实机验收。旧 `250702` XML 仅 40 对象，不能混用配置。[官方新版 ZIP](https://www.myactuator.com/_files/archives/cab28a_f94084d537ab4cbf87d90bd780e7120f.zip)

两版均只有通用 `MT_Device`，没有四个精确订货型号条目。新版顶层 Vendor `0x202008`、ProductCode `0`、Revision `0x00010000`；其 `0x1018` 默认字节却对应 Vendor `0x282`、Revision `0x10`。这是模板内不一致，不能据任一默认值伪造实机身份。需读取每台从站身份、实际硬件/固件、PDO 和单位后，再锁定匹配文件。[原厂固件页](https://www.myactuator.cn/gu) 要求联系销售取得最新固件，本次未联系、未取得受控固件或刷写。

| 运行接口 | 公开证据与边界 |
|---|---|
| 驱动使能 | 协议 V2.0 PDF pp11–12、17–18：`0x6040` 控制字、`0x6041` 状态字，状态机使能；实施前必须按返回状态推进，不能以固定延时发送命令串 |
| 运动与反馈 | 默认 Rx `0x1600` 含控制字、位置/速度/转矩目标、最大转矩、模式；Tx `0x1A00` 含状态、位置/速度/转矩反馈、`0x603F` 错误与模式反馈；具体字宽见 JSON |
| 温度/电压 | `0x2009` 电机温度、`0x200C` 驱动温度、`0x200A` 电压存在；单位、测点与实际保护阈值必须对应协议/固件核实 |
| Quick stop | PDF p50 在 Operation Enabled 状态下给 `0x6040=0x0002`；在 `0x605A=0` 时按 `0x6085` 减速后进入 Switch On Disabled。这是该厂文档定义，不能换成未经核验的通用 CiA402 假设 |
| 故障响应 | `0x605E` 有对象，但本次检查的协议和 ESI 未提供支持值与完整动作/时序表；XML 原始默认 `2000` 按小端是 32，不能误读成 2 |
| 故障复位 | PDF pp12、55–56 说明 `0x6040` bit7 上升沿 / `0x0080` 触发系统复位，运行参数回到默认后需重配；不能假定复位后保留全部限值 |
| 抱闸 | 最新 XML 与协议未找到抱闸命令或状态对象；未证明 `0x6041` 提供机械抱闸到位反馈 |
| 失联、看门狗与停止安全 | 缺完整时限和转矩/抱闸反应表；未取得 STO / SBC / SS1 / FSoE 认证及硬接线端口证据。普通 PDO Disable / Quick stop **不是 STO** |

CAN 是单独的接口证据：共享包中的 CAN V4.4 PDF pp131–133 给 `0x77` 释放、`0x78` 锁闸，并称失电状态为锁闸；但没有接合时间。PDF pp53–54 的 `0x9A.DATA[3]` 只回读控制指令状态（1=释放、0=锁闸），不是机械到位反馈。PDF p68 要求带闸型号在 `0xA1` 转矩指令前另发 `0x77`；pp138–139 的 `0xB3` 是 CAN 超时保护，0 禁用，文档称超时切断输出并锁闸。**这些不能自动映射为 EtherCAT 对象、EtherCAT 断线反应或 N 型的抱闸能力**，仍需确认所购固件和双总线控制仲裁。[CAN / EtherCAT 原厂共享包](https://www.myactuator.com/_files/archives/cab28a_be98b58973d34f7aaa50bdf3f2aa12ed.zip)

协议页码与 XML 对象字段已列入 JSON；新 XML 的 `0x200D…0x2011` 在协议 V2.0 中未找到对应说明。额定电流等 XML 默认零值属于模板，不是型号电流额定。[协议包](https://www.myactuator.com/_files/archives/cab28a_be98b58973d34f7aaa50bdf3f2aa12ed.zip)

只读检查官方中文站 `IGH 260620` 样例还发现 `main.cpp` 填充 PDO 仍用 `0x5FFE`，新版 ESI 则为 Rx `0x2FFD` / Tx `0x2FFE`；样例 `quick_stop` / `fault_reset` 标志的设置未在主循环消费。该样例未执行，不能直接作为本项目的停止实现或验收工具。[官方 SDK ZIP](https://cloud-1251007531.bcdn8.com/maita0712/uploads/20260630/MyActuator_IGH%283%29.zip)

## 5. 输出螺孔：图纸名义深度仍不足以冻结长度

统一坐标为输出安装接触环面 `z=0`、向外为 `+z`。孔阵已从原厂 STEP 独立提取，见 [接口证据](sources/rh-interface-extraction.json)。下列 STEP 数值是已核光孔段，不是保证牙段。

| 精确候选简写 | 图面孔阵 | 图面螺纹深度 | 图面避让孔深 | STEP 已核光孔段 |
|---|---|---:|---:|---|
| RH25 B | 16×M4，PCD77 | 6 mm | 13 mm | Ø4.4，z=−3.5…0 |
| RH20 B | 16×M3，PCD62 | 6 mm | 10.5 mm | Ø3.4，z=−3…0 |
| RH17 B | 16×M3，PCD54，非均布 | 6 mm | 9.6 mm | Ø3.4，z=−3…0 |
| RH14 N | 8×M3，PCD44，非均布 | 5 mm | 9 mm | Ø3.4，z=−3…0 |

依据各型号选定 B/N 的 2D-A / 2D-A0 图 PDF p1 和配对 STEP，哈希在 JSON；[官方下载入口](https://www.myactuator.com/downloads-rhseries)。**不能把避让深度减名义牙深，当作满牙起点；不能把光孔段与牙深相加，就当作最大允许插入。** STEP 未建真实螺纹，且名义深度可能包含钻尖、导入与不完整牙。需要按版本给出有效满牙起/止、盲孔底及内部旋转件最小间隙、最大总深入量。

用户手册 PDF p23 表 4-1 的通用 M3×0.5 / M4×0.7 扭矩分别为 17 / 40 kgf·cm，即约 1.667 / 3.923 N·m，并要求螺纹胶、分阶段对角紧固。表未充分限定螺钉等级、摩擦、母材和胶型，不能据此放行本项目薄转接环或未知有效牙长。当前 OEM 输出螺钉长度继续保留 TBD；已做装配几何检查不能替代啮合强度与防顶底确认。

## 6. 下一步需要的受控资料与验收证据

| 优先级 | 需要取得的具体内容 | 会关闭的决定 |
|---|---|---|
| P0 | 四个订货代码的零速转矩/相电流/温升曲线、测点、安装条件、环境降额与重复周期 | 2 kg 工件及重头情景下的持续姿态保持 |
| P0 | B 闸最小输出保持能力、转矩所在侧、失电/欠压/故障动作顺序、释放/接合时间、线圈消耗、允许停止能量及反馈能力 | 重力轴停止与掉电策略；J7 N 的额外保持方案 |
| P0 | 实机版本、ESI / 固件配对、只读身份、使能/禁能/Quick stop/故障/失联时序和默认保护参数 | 主站配置与停止状态机；独立安全架构 |
| P0 | 母线峰值/连续输入、启动与抱闸瞬态、RES 斩波器及电阻定额、阈值与能量 | 外置电源、预充、熔断、接触器、再生吸收 |
| P0 | 版本受控剖面：满牙起止、允许总深入、内部旋转间隙、紧固件等级/扭矩 | 各 OEM 输出螺钉长度和加工图放行 |
| P1 | 所有连接器准确对插/线侧图、完整接插件料号、屏蔽/接地与 BAT 电池要求 | 线束制造和可维护接口 |

在这些资料与台架证据取得前，可以继续完成几何、CAD、候选 BOM 和离线控制接口，但不得把“有 EtherCAT / 有抱闸 / 目录转矩够大”写成整臂已能可靠承载和安全停止。

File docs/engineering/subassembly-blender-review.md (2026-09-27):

<!-- SPDX-License-Identifier: CC-BY-NC-4.0 -->
<!-- Required Notice: Odradek — Auromix contributors (https://github.com/Auromix/odradek) -->
# 原生 Blender 分组件检查模型

状态：**R4-SUBASSEMBLY-REVIEW-01，三个可编辑场景、五张渲染、四指层级检查完成。** 这是已计算原创几何的检查入口；未将新连接、根部驱动和真实灯板合成为制造装配。

[下载原生 .blend](../../engineering/generated/component-reviews/odradek-r4-subassemblies.blend)；[输入哈希与校验记录](../../engineering/generated/component-reviews/evidence.json)。打开后通过 Blender 顶部 Scene 选择器切换场景。

| 场景 | 几何和操作 | 未包含的部分 |
|---|---|---|
| `01_LINK56_connection` | J5→J6 六个原创金属零件，按实际装配矩阵摆放 | 原厂关节、40 个紧固件和电缆；尺寸和装配检查见 [LINK56](link56-structure-study.md) |
| `02_anchored_base` | 底板、背板、双环及四支柱，共八件 | 桌面、锚栓和原厂关节；背板间隙用于桌架夹固，不能从渲染推断自立稳定性 |
| `03_CONTACT02_four_axes` | 16 个指片/灯窗/软垫、6 个旧中心/相机占位及1个数学圆柱，共23网格；四个独立旋转父节点 | 根部驱动、真实 PCB、保持件和动态线束 |

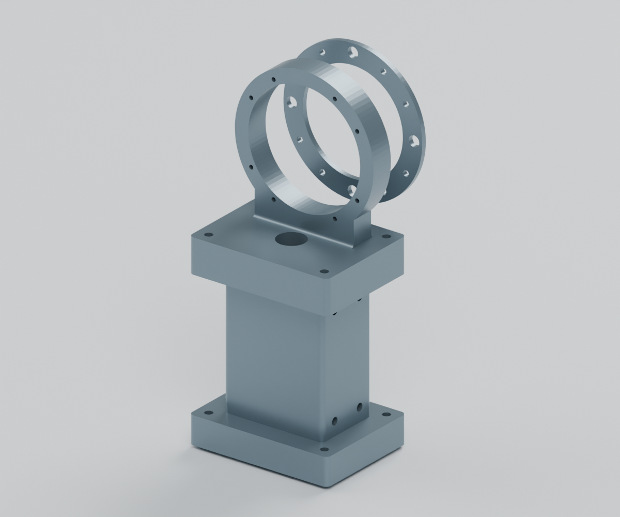
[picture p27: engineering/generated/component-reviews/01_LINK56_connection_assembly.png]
J5到J6原创连接


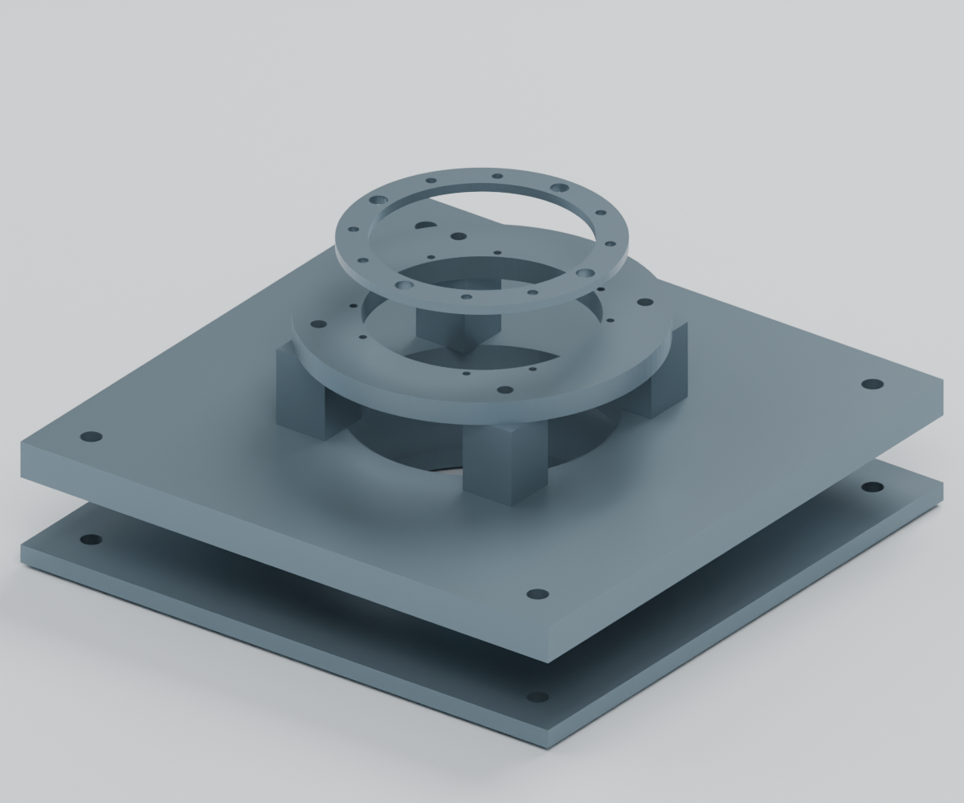
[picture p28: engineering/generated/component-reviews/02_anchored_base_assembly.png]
固定底座


## 四指操作

`FINGER_UR/UL/LL/LR` 是独立旋转节点，网格通过父级逆矩阵保留其原 STEP 姿态。上指与下指根部有50 mm轴向错位；镜像来自真实几何坐标，不把同一片任意缩放成另一片。

| 帧 | 姿态 | 上指 / 下指 |
|---|---|---|
| 1 | 展开，数学圆柱隐藏 | 0° / 0° |
| 120 | CONTACT-02 的 Ø80×40 mm 侧面接触案例，圆柱 z=115…155 mm | 97.790717° / 102.219295° |
| 220 | 空载研究收拢限位，圆柱隐藏 | 109° / 122° |
| 360 | 回到展开 | 0° / 0° |

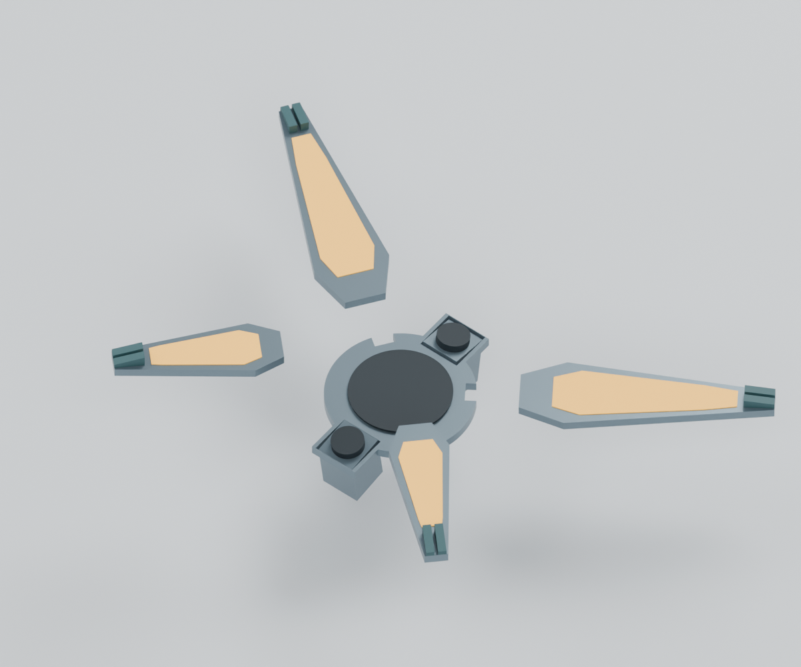
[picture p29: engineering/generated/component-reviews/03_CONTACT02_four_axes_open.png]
展开


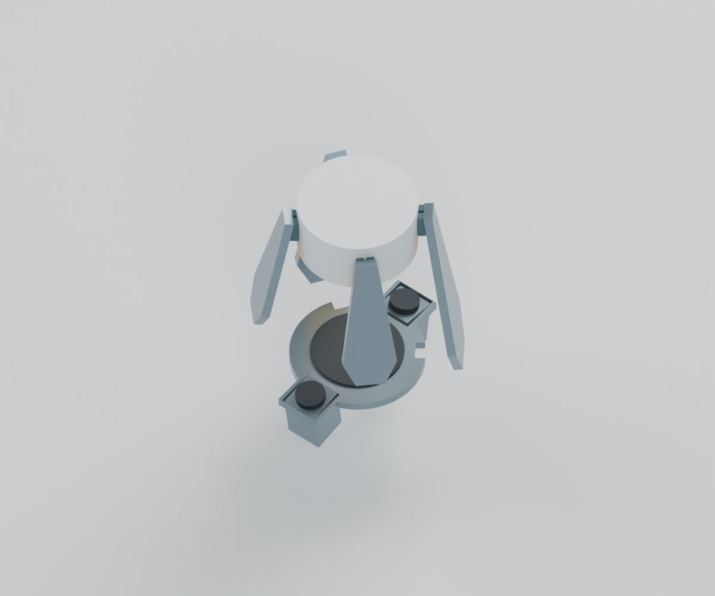
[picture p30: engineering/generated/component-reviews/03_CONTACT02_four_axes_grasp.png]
指定圆柱接触姿态


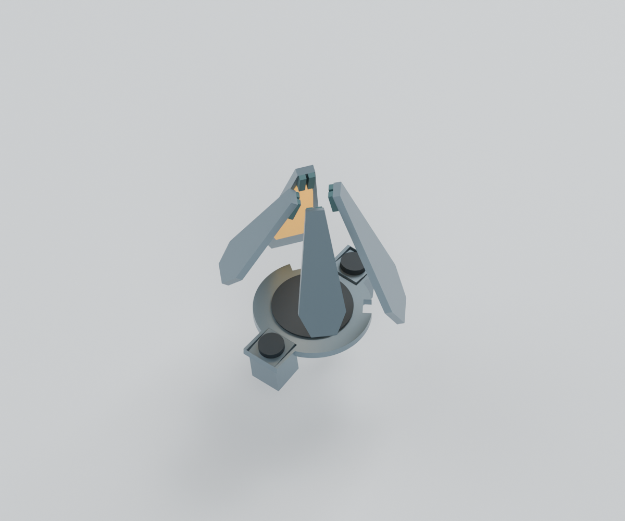
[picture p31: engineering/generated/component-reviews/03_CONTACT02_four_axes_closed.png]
空载收拢限位


收拢限位保留指间间隙，不表示四片密封或能夹住任意小物体。帧间动画只插值角度；中途显隐工件用于对照，**不模拟接近、夹紧、搬运、释放或实际执行器速度/占空比**。灯窗仍是0.6 mm光学面占位。中央圆屏没有添加虚构像素电路。

## 数据一致性与复现

原创 STEP 以0.05 mm线性、0.12 rad角度公差三角化；保存为米制网格，界面按毫米显示。每个产品对象保留源文件路径及 CAD 体积，报告记录全部源 STEP SHA-256。展示地面、灯光与相机另有明确名称，不计为产品件。

对每指在展开、接触、收拢三姿态，读取 Blender 实际父子变换后的顶点，与独立 Rodrigues 旋转比较：12 项通过，最大差约 **0.0000084 mm**。这验证层级变换，不是网格精度、实体干涉或载荷试验。五张完整渲染已经人工查看，无截断；指定工件仅出现在接触图。

依赖已有 LINK56、底座及 CONTACT-02 STEP，从仓库根目录运行：

```sh
python engineering/export_component_reviews.py --output /tmp/odradek-component-meshes.json
blender --background --factory-startup --python engineering/blender_component_reviews.py -- --mesh-json /tmp/odradek-component-meshes.json
```

原始7＋4整臂布局 `.blend` 保留为历史基线。本分组件包没有覆盖该文件，也不能把三场景的各自检查相加当作新整机验证。

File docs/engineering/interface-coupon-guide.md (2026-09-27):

# R4 输出接口试装样片

这四片用于取得实际关节后，手动检查输出孔阵、中心凸台避让和工具进入空间。**它们是 4 mm 厚的无载打印样片，不是机械臂承力转接件。** 当前只完成几何生成与文件重读检查，尚未完成实物试装。

[四页尺寸图 PDF](../../engineering/generated/interface-coupons/PDF/ODR-interface-coupons-R4.pdf) 包含每个孔的坐标和角度、图号、中心孔与外径、厚度、孔径、PCD，以及打印与检验说明。主视图按 A4 横向 1:1 绘制；打印 PDF 时选择“实际大小”，不要选择“适合页面”。尺寸标注优先于纸张实测。

## 对应件与尺寸

全部单位 mm，厚度均为 4.0。外径等于该关节输出外圆定位直径加 8；中心孔等于中央凸台直径加 0.6。中心孔是避让孔，**不形成定位配合**。

| 样片图号 | 对应关节 | 外径 | 中心贯通孔 | 固定孔 | PCD | 图案 |
|---|---|---:|---:|---|---:|---|
| ODR-CPN-RH14-N-R4 | EPS-RH-14-100-E-N-D | 58.0 | 37.6 | 8×Ø3.5贯通 | 44.0 | 非均布，按坐标 |
| ODR-CPN-RH17-B-R4 | EPS-RH-17-100-E-B-D | 68.0 | 47.6 | 16×Ø3.5贯通 | 54.0 | 非均布，按坐标 |
| ODR-CPN-RH20-B-R4 | EPS-RH-20-100-E-B-D | 78.0 | 55.6 | 16×Ø3.5贯通 | 62.0 | 均布，保留提取相位 |
| ODR-CPN-RH25-B-R4 | EPS-RH-25-100-E-B-D | 93.0 | 69.6 | 16×Ø4.5贯通 | 77.0 | 均布，保留提取相位 |

数据来自 [原厂 STEP 独立提取记录](sources/rh-interface-extraction.json) 的 `unified_joint_interface.output_holes`。该坐标系原点是输出环形接触面的轴心，+Z 朝向输出端；样片底面 z=0，顶面 z=4。孔位保持原厂 CAD 的装配相位，尚未等同于编码器电气零位。可以旋转整片找正，不能镜像、缩放或重新均布孔阵。

原厂配套 STEP/PDF 只在本地用于核验，未随本仓库再分发；来源和版本见 [关节候选](hardware/joint-candidates.md)。本样片的独立几何是根据接口尺寸重新生成的。

## 下载与复现

| 型号 | STEP | STL | DXF | 坐标 CSV |
|---|---|---|---|---|
| RH14-N | [STEP](../../engineering/generated/interface-coupons/STEP/ODR-CPN-RH14-N-R4.step) | [STL](../../engineering/generated/interface-coupons/STL/ODR-CPN-RH14-N-R4.stl) | [DXF](../../engineering/generated/interface-coupons/DXF/ODR-CPN-RH14-N-R4.dxf) | [CSV](../../engineering/generated/interface-coupons/coordinates/ODR-CPN-RH14-N-R4.csv) |
| RH17-B | [STEP](../../engineering/generated/interface-coupons/STEP/ODR-CPN-RH17-B-R4.step) | [STL](../../engineering/generated/interface-coupons/STL/ODR-CPN-RH17-B-R4.stl) | [DXF](../../engineering/generated/interface-coupons/DXF/ODR-CPN-RH17-B-R4.dxf) | [CSV](../../engineering/generated/interface-coupons/coordinates/ODR-CPN-RH17-B-R4.csv) |
| RH20-B | [STEP](../../engineering/generated/interface-coupons/STEP/ODR-CPN-RH20-B-R4.step) | [STL](../../engineering/generated/interface-coupons/STL/ODR-CPN-RH20-B-R4.stl) | [DXF](../../engineering/generated/interface-coupons/DXF/ODR-CPN-RH20-B-R4.dxf) | [CSV](../../engineering/generated/interface-coupons/coordinates/ODR-CPN-RH20-B-R4.csv) |
| RH25-B | [STEP](../../engineering/generated/interface-coupons/STEP/ODR-CPN-RH25-B-R4.step) | [STL](../../engineering/generated/interface-coupons/STL/ODR-CPN-RH25-B-R4.stl) | [DXF](../../engineering/generated/interface-coupons/DXF/ODR-CPN-RH25-B-R4.dxf) | [CSV](../../engineering/generated/interface-coupons/coordinates/ODR-CPN-RH25-B-R4.csv) |

运行 [build_interface_coupons.py](../../engineering/build_interface_coupons.py) 需要 Python、CadQuery、NumPy、trimesh、ezdxf、reportlab，以及含中文字符的 TrueType 字体。原厂 STEP 不参与本步骤，输入是已经提取的 JSON。

```sh
python engineering/build_interface_coupons.py --font /path/to/Chinese-capable-font.ttf
```

可通过 `--source` 和 `--output` 显式指定输入和输出目录；脚本没有用户机器目录硬编码。`verification.json` 记录输入提取文件 SHA256、每件原厂源 STEP 的 SHA256、输出几何校验和文件哈希。DXF 使用毫米，只有外轮廓、中心孔和螺钉孔三个图层；它不包含 CNC 工艺、螺纹、沉孔或表面处理定义。

## 打印和手动试装

建议 PLA 或 PETG、0.20 mm 层高、4 道壁、100% 填充；XY 平面直接贴打印床面，+Z 向上。此件不需要支撑。不要通过整体缩放补偿小孔，否则 PCD 和所有孔中心位置也会改变；先做打印机孔径校准，再使用局部孔补偿并记录数值。

打印试装阶段建议检验：外径和厚度相对标称 ±0.20，孔径为标称 +0.20/0，孔中心的 X/Y 坐标分别在 ±0.15 内。这些是本次试装样片的评估建议，不是经验证的打印机能力，也不是后续金属连接件的制造公差。最窄孔间材料区域需检查是否破损，轻微清理毛刺后再试。

试装时关节必须断电并被独立稳固支撑：

1. 核对收到的完整型号、制动版本及资料版本；不同版本不能仅凭外形复用本片。
2. 将样片轻放在输出环面，确认中心孔避开凸台，板面没有被中央凸台顶起。
3. 转动整片观察每个孔的对应关系，记录不可达、干涉、需要工具避让的位置。不要强压、敲入或靠拧紧螺钉拉平打印件。
4. 原关节的螺纹在孔内后缩；本设计没有选定螺钉长度。须先确认孔深、螺纹始端、有效啮合及底部余量，不能直接套用“板厚 + 6 mm”之类经验长度。
5. 记录实际尺寸、照片、孔偏差、打印材料和补偿设置，再决定承力转接件的配合和结构。

本次样片不承担关节、臂杆、末端或工件重量，不用于通电运动、夹持力测试或 2 kg 负载验证。样片孔阵检查通过，也只说明对应实物的孔位和避让关系通过这项检查。

## 已完成的文件检查

- CadQuery 实体有效、单一实体、解析体积相符；顶面闭合边界数量与中央孔 + 螺钉孔数量相符。
- STEP 导出后重新导入，有效性、单实体、体积通过。
- STL 重读后水密、单体；Euler 数与每件贯通孔总数一致，离散体积误差小于 0.3%。
- DXF 重读审计通过，单位为毫米；圆实体数、孔坐标及孔径与源参数一致。
- 四页中文 PDF 逐页渲染检查，确认文字、孔号、坐标表和边界布局。

可核查结果见 [verification.json](../../engineering/generated/interface-coupons/verification.json)。这些是数字文件检查，不代替实体试装或制造验收。

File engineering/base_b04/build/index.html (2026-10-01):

# ODRADEK / B04 底座

真实 CAD 衍生模型 · 后沿桌夹 · 内收盒架 · 服务 PCB

B04-P2 · 原型装配审查

ASSEMBLY / 装配

总装看内部后侧侧视

桌厚

展开程度 0%

MODULES / 模块显示

PARTS / 零件

点击零件名称聚焦查看。拖动旋转，滚轮缩放；按住 Shift 拖动平移。

STEP 总装BlenderGLB

坐标：+Y 向桌内 · Z = 0 为桌面
盒体为 180 × 150 × 50 mm 检具；完整柔性线束待深化
展开视图示意模块拆分。实体负载、桌板接触与带电测试尚待验证。

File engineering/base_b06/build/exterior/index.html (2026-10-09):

# ODRADEK / B06 底座

紧凑一体盾形 · 斜肩与四瓣浅脊 · 内藏固定

数字装配审阅 · 实物试装待验证

ASSEMBLY / 装配状态

总装外罩拆开后盖拆开爆炸视图

拆开程度0%

桌厚

MODULES / 模块显示

PARTS / 零件与尺寸

选择零件可查看尺寸、工艺和当前状态。

拖动旋转 · 滚轮缩放
按住 Shift 拖动或右键拖动平移

前侧后侧接口俯视底面固定适配视野

总装 · 坐标单位 mm
+Y 向桌内 · Z = 0 为桌面
拆开视图用于识别装配关系；未包含完整承载桌夹；未模拟拆装路径与柔性线缆。

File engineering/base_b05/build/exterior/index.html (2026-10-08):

# ODRADEK / B05 底座

盾形外罩 · 隐藏接线仓 · 可替换接口组件

数字装配审阅 · 实物试装待验证

ASSEMBLY / 装配状态

总装外罩拆开后盖拆开爆炸视图

拆开程度0%

桌厚

MODULES / 模块显示

PARTS / 零件与尺寸

选择零件可查看尺寸、工艺和当前状态。

拖动旋转 · 滚轮缩放
按住 Shift 拖动或右键拖动平移

前侧后侧接口俯视桌夹下方适配视野

总装 · 坐标单位 mm
+Y 向桌内 · Z = 0 为桌面
拆开视图用于识别装配关系；未模拟拆装路径与柔性线缆。

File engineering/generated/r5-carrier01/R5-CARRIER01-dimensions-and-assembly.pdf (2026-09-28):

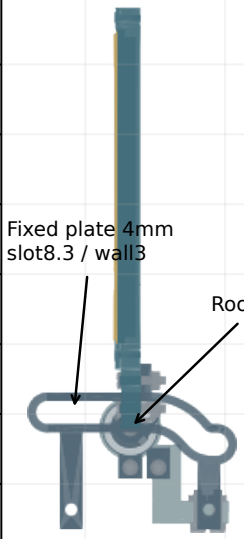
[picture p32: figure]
Fixed plate 4mm slot8.3 / wall3

50 | 100
Branch radial X [mm]

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
Head Z [mm]

| Root Z20

Side / folded at R66 / upper petal

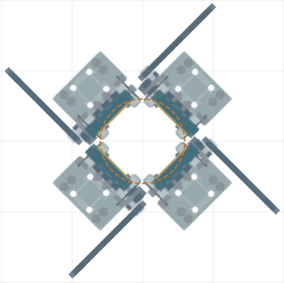
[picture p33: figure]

−100 | −50 | 0 | 50 | 100
| | Head X [mm]

−100

−50

0

50

100

Head Y [mm]

C4 support / R31 / bilateral petals

# R5 / one radial carrier + split hinge + fixed guide

Frozen stage inputs: rootZ20; R31..91; q0..90; a8 / phase-45deg. Fixed slotY30..34. 607/8-2Z: 8x19x6, centersY+/-16; CFS4: D8 x5 rolling width atY29.5..34.5.
Guide attachment bores: D4.5, head(X,Z)=(45,-9),(94,-9); no palm attachment model.

The C4 steel guides are exposed in this prototype. No enclosure proves a mirror-symmetric exterior. No radial rail, motor, differential, return spring, hard stops or working cameras are included.
The D60 x8 disc is a clearance gauge only. Neither 1-second motion nor a 2kg grasp is qualified.
Odradek — Auromix contributors (https://github.com/Auromix/odradek) | CC BY-NC4.0 | nominal packaging / not manufacture release | 1/2

Actual solids / +Y bearing and follower side

# Axial stack / service access / load path

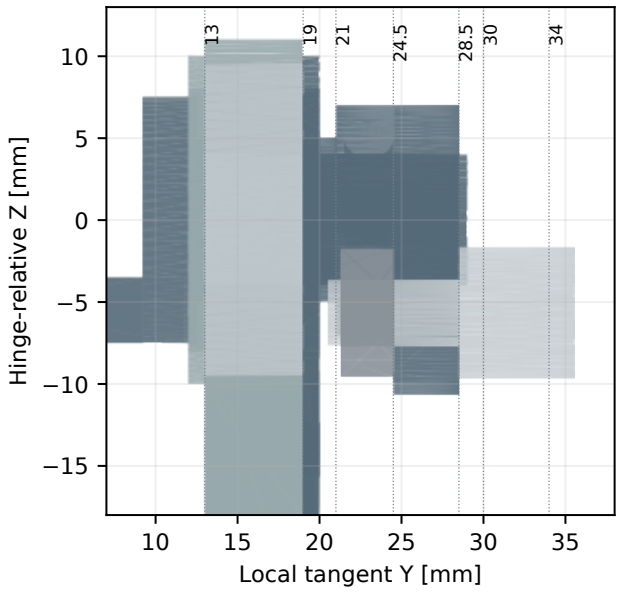
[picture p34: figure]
Local tangent Y [mm]; Hinge-relative Z [mm]

Cam seat:4mm
D4H6 candidate / backingD10 AF7 nut:3.2mm
Thread tail:0.8mm nominal
Seat -> guide gap:1.5mm
Track rolling-edge allowance:0.5mm

Rear service relief:D10.4
Main seat hole ligament:2mm
D3 pin:custom, unretained
Inner spacer:D10/D8 x2

1 Attach petal to U cradle with four M3 screws, washers and rear nuts.
2 Slide separate bearing pedestals onto short journals; fit caps and foot bolts. 3 Assemble CFS on the detached crank: hold the head, turn the supplied nut.
4 Fit spacer and crank to shaft, then crosspin. Install the fixed guide last.
5 Connect to a separately qualified rail/backbone; no complete palm is supplied.

Load: face -> FORM02 frame -> M3 interface -> steel cradle/short shaft -> crank/pin -> CFS -> fixed guide. Bearing reaction also flows through two pedestals into the radial foot. Catalog ratings do not qualify
this custom load path. Fits, pin retention, fastener preload, fatigue and impact stops remain open.
Odradek — Auromix contributors (https://github.com/Auromix/odradek) | CC BY-NC4.0 | nominal packaging / not manufacture release | 2/2

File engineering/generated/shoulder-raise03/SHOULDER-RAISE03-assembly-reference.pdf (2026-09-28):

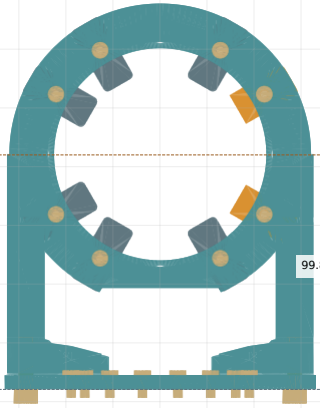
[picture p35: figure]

−60 | −40 | −20 | 0 | 20 | 40 | 60 | 80
X [mm]

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
Z [mm]

132.0 overall

99.8 axis rise

Front X-Z | +Y view

# SHOULDER-RAISE03 | Local assembly reference

World home [mm] / J1 Z105.2 / J2 Z205.0 / all 39 parts follow J1 only

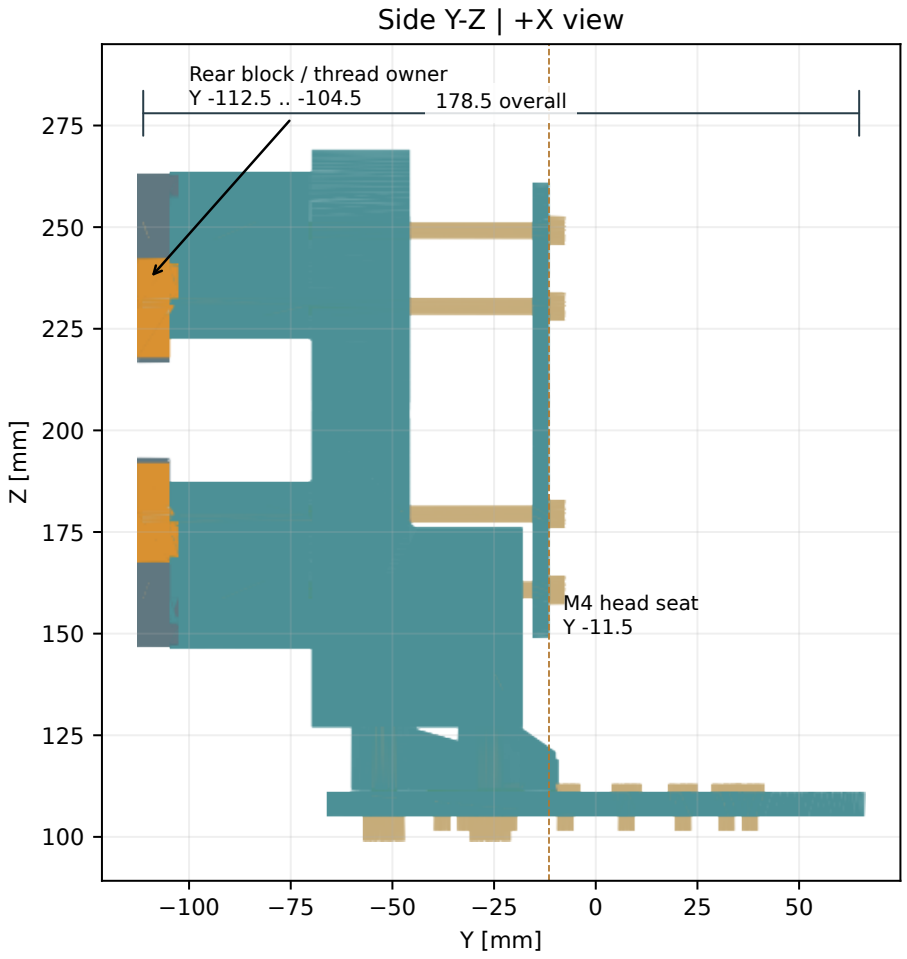
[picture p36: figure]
178.5 overall; Rear block / thread owner Y -112.5 .. -104.5; M4 head seat Y -11.5; Side Y-Z | +X view

Included: 11 original metal parts + 28 nominal hardware envelopes. OEM motors are omitted from public CAD.

Original metal: 1.227752 kg | primary planning total: 1.427752 kg
Orange: PORT01 trimmed blocks 1 / 8. Gold: hardware envelopes. Shoulder height and forward clearance unchanged. Nominal geometry only; not a manufacturing drawing. Tolerances, preload, plugs and full thread lengths remain open.
Odradek — Auromix contributors (https://github.com/Auromix/odradek) | CC BY-NC 4.0 | 1 / 2

# Connections and geometry-only print set

8 x Fabory 07000.040.100 (candidate) M4 x 0.7 x 100, class 12.9, plain
Max head D7 x H4; AF3; thread b20

Y stack [mm]
Head bearing plane: -11.5
Thread start: -91.5
Block entry: -104.5
Screw tip: -111.5
Block rear: -112.5

Grip 93 / geometric entry 7 / tip gap 1 Effective complete-thread entry: TBD

Nominal head bearing footprint
22.580 mm2 each at max head diameter Same-force pressure ratio vs old: 1.1088 No preload / wrench torque selected.

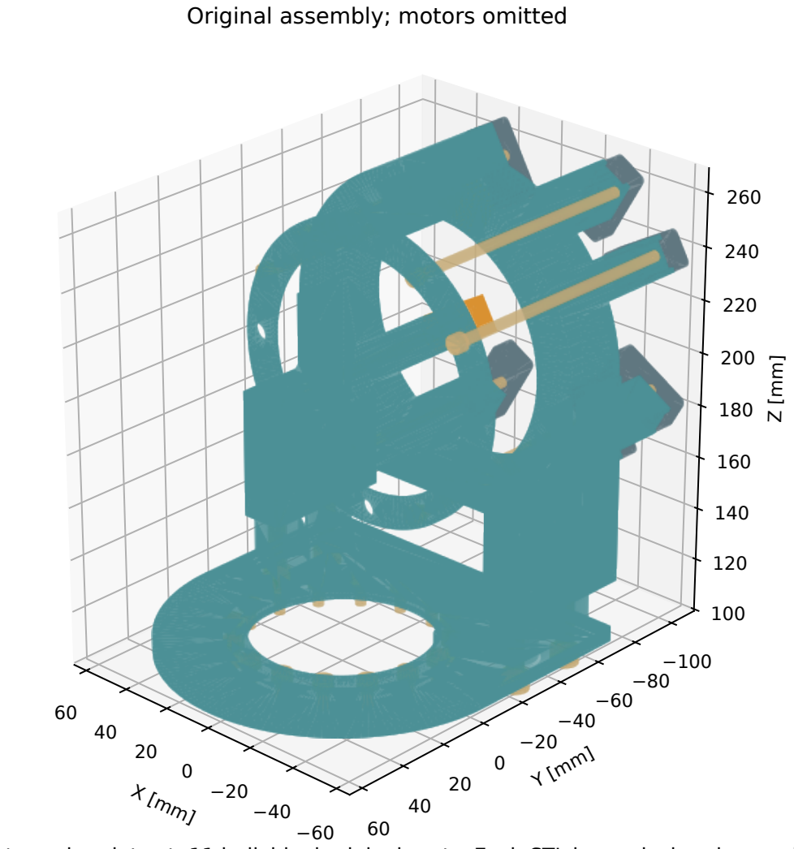
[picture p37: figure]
Original assembly; motors omitted

Geometry-only print set: 11 individual original parts. Each STL has a declared reversible print-frame transform.
Do not energize motors or apply a payload/preload through printed parts. No inserts or printed threads are qualified.
Odradek — Auromix contributors (https://github.com/Auromix/odradek) | CC BY-NC 4.0 | 2 / 2

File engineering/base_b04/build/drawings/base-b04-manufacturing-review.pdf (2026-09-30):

# ODRADEK / 底座加工与装配审查

### 真实 STEP 重读 / 全局坐标 X 左右、+Y 向桌内、+Z 向上 / 原创零件名义几何

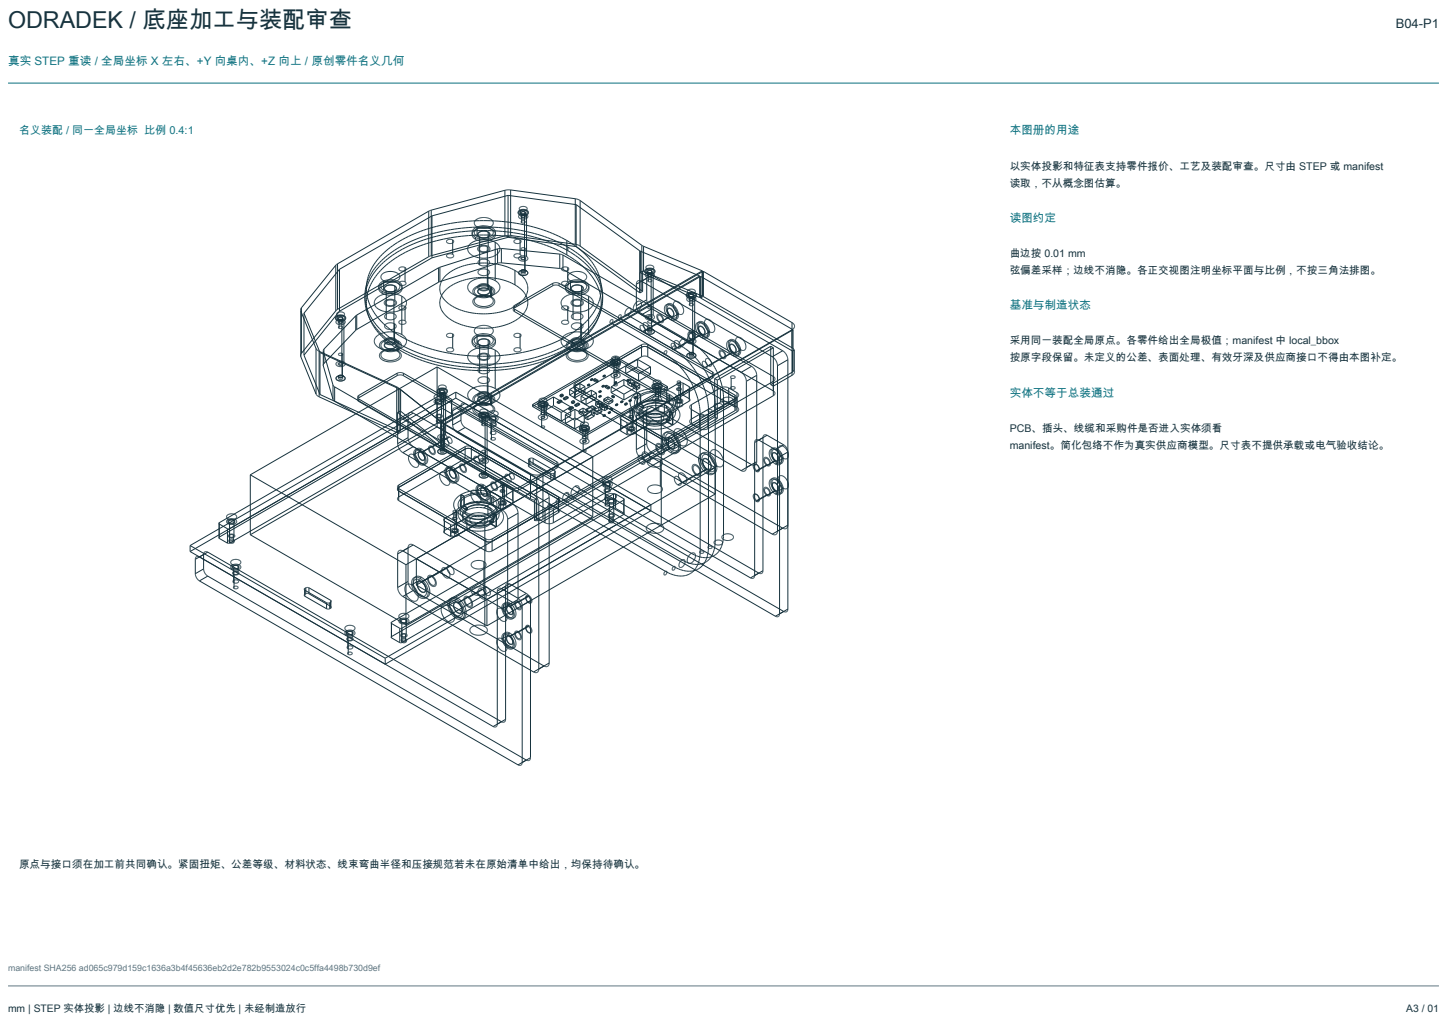
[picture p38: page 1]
mm | STEP 实体投影 | 边线不消隐 | 数值尺寸优先 | 未经制造放行; manifest SHA256 ad065c979d159c1636a3b4f45636eb2d2e782b9553024c0c5ffa4498b730d9ef; 名义装配 / 同一全局坐标 比例 0.4:1; 本图册的用途; 读图约定; 基准与制造状态; 实体不等于总装通过

以实体投影和特征表支持零件报价、工艺及装配审查。尺寸由 STEP 或 manifest
读取，不从概念图估算。

曲边按 0.01 mm
弦偏差采样；边线不消隐。各正交视图注明坐标平面与比例，不按三角法排图。

采用同一装配全局原点。各零件给出全局极值；manifest 中 local_bbox
按原字段保留。未定义的公差、表面处理、有效牙深及供应商接口不得由本图补定。

PCB、插头、线缆和采购件是否进入实体须看
manifest。简化包络不作为真实供应商模型。尺寸表不提供承载或电气验收结论。

原点与接口须在加工前共同确认。紧固扭矩、公差等级、材料状态、线束弯曲半径和压接规范若未在原始清单中给出，均保持待确认。

# ODRADEK / 加工件与来源清单

仅列 manifest 中带加工 STEP 的零件；采购件、紧固件和 PCB 另见对应清单

manifest SHA256 ad065c979d159c1636a3b4f45636eb2d2e782b9553024c0c5ffa4498b730d9ef

特征 / 属性路径 | 数值、方向和限定说明（长度默认 mm；其他单位以字段名为准）
B04-101-DECK | 数量 1 | 材料 6061-T651 | 工艺 CNC profile + mill + drill/tap | B04-101-DECK.step
B04-102-CPLATE-L | 数量 1 | 材料 S355 | 工艺 Profile cut oversize; finish mill + drill/tap | B04-102-CPLATE-L.step
B04-102-CPLATE-R | 数量 1 | 材料 S355 | 工艺 Profile cut oversize; finish mill + drill/tap | B04-102-CPLATE-R.step
B04-103-BRIDGE | 数量 1 | 材料 6061-T651 | 工艺 CNC mill + drill/tap | B04-103-BRIDGE.step
B04-104-FLANGE | 数量 1 | 材料 6061-T651 | 工艺 CNC turn/mill + drill/tap | B04-104-FLANGE.step
B04-105-POST-1 | 数量 1 | 材料 6061-T651 | 工艺 Turn + drill/tap | B04-105-POST-1.step
B04-105-POST-2 | 数量 1 | 材料 6061-T651 | 工艺 Turn + drill/tap | B04-105-POST-2.step
B04-105-POST-3 | 数量 1 | 材料 6061-T651 | 工艺 Turn + drill/tap | B04-105-POST-3.step
B04-105-POST-4 | 数量 1 | 材料 6061-T651 | 工艺 Turn + drill/tap | B04-105-POST-4.step
B04-106-TOPPAD--1 | 数量 1 | 材料 silicone | 工艺 Knife/waterjet cut | B04-106-TOPPAD--1.step
B04-107-PRESSPAD--1 | 数量 1 | 材料 6061-T651 | 工艺 CNC mill/drill/tap | B04-107-PRESSPAD--1.step
B04-108-LOWPAD--1 | 数量 1 | 材料 silicone | 工艺 Knife/waterjet cut | B04-108-LOWPAD--1.step
B04-109-FOOT-CAGE--1--1 | 数量 1 | 材料 PETG | 工艺 FDM; 0.2 layer, 4 walls, solid around screws | B04-109-FOOT-CAGE--1--1.step
B04-109-FOOT-CAGE--1-1 | 数量 1 | 材料 PETG | 工艺 FDM; 0.2 layer, 4 walls, solid around screws | B04-109-FOOT-CAGE--1-1.step
B04-106-TOPPAD-1 | 数量 1 | 材料 silicone | 工艺 Knife/waterjet cut | B04-106-TOPPAD-1.step
B04-107-PRESSPAD-1 | 数量 1 | 材料 6061-T651 | 工艺 CNC mill/drill/tap | B04-107-PRESSPAD-1.step
B04-108-LOWPAD-1 | 数量 1 | 材料 silicone | 工艺 Knife/waterjet cut | B04-108-LOWPAD-1.step
B04-109-FOOT-CAGE-1--1 | 数量 1 | 材料 PETG | 工艺 FDM; 0.2 layer, 4 walls, solid around screws | B04-109-FOOT-CAGE-1--1.step
B04-109-FOOT-CAGE-1-1 | 数量 1 | 材料 PETG | 工艺 FDM; 0.2 layer, 4 walls, solid around screws | B04-109-FOOT-CAGE-1-1.step
B04-201-CRADLE-L | 数量 1 | 材料 6061-T651 | 工艺 CNC profile + drill/tap | B04-201-CRADLE-L.step
B04-201-CRADLE-R | 数量 1 | 材料 6061-T651 | 工艺 CNC profile + drill/tap | B04-201-CRADLE-R.step
B04-202-TRAY | 数量 1 | 材料 6061-T651 | 工艺 CNC profile + drill/tap | B04-202-TRAY.step
B04-203-STOP-REAR | 数量 1 | 材料 6061-T651 | 工艺 Mill + drill | B04-203-STOP-REAR.step
B04-203-STOP-FRONT | 数量 1 | 材料 6061-T651 | 工艺 Mill + drill | B04-203-STOP-FRONT.step
B04-301-COVER-REAR | 数量 1 | 材料 PETG | 工艺 FDM; 0.2mm layer; 4 walls; supports under roof | B04-301-COVER-REAR.step
B04-301-COVER-FRONT | 数量 1 | 材料 PETG | 工艺 FDM; 0.2mm layer; 4 walls; supports under roof | B04-301-COVER-FRONT.step

# ODRADEK / 共用基准与声明

### 逐字沿用参数声明；孔位置公差的具体基准与检验方法仍需制造评审

manifest SHA256 ad065c979d159c1636a3b4f45636eb2d2e782b9553024c0c5ffa4498b730d9ef

特征 / 属性路径 | 数值、方向和限定说明（长度默认 mm；其他单位以字段名为准）
coordinates.x | right
coordinates.y | inward from desk rear edge
coordinates.z | up from desk top
tolerances.machined_unless_noted_mm | 0.2
tolerances.mounting_hole_position_mm | 0.1
tolerances.printed_unless_noted_mm | 0.5
tolerances.mating_face_flatness_mm | 0.1
notes | [All tapped holes use pilot cylinders in STEP, with complete thread callouts in feature tables., Base-only interface is new; arm motor adapter is a later module., 48 mm rear design clearance is a prototype allocation, not a measured installation minimum., No load-bearing printed components; never test the full arm on an unqualified desktop.]
B04-101-DECK | Profile R4; metal top z14, desk pad plane z0. Side tapped holes drill 17 deep, full thread >=14. Bottom flange-post counterbores seat at z10.5; screw heads remain above z2.5.
B04-102-CPLATE-L, B04-102-CPLATE-R | All profile corners R5. 10 mm certified steel plate; coat after machining; mask mating faces. Left/right differ by installation only; hole axes shown from outer face.
B04-103-BRIDGE | M12 thrust screws: certified DIN6332-5.8, AF6 drive; no ordinary cup-point grub screws.
B04-104-FLANGE | Base test interface only. OD160 / ID60, PCD120: 8 x M6 phase22.5deg. Face z58 flatness0.1; no commercial motor compatibility claimed.
B04-105-POST-1, B04-105-POST-2, B04-105-POST-3, B04-105-POST-4 | OD22 x32; M8x1.25-6H through; end faces parallel0.05. Four identical posts.
B04-106-TOPPAD--1, B04-106-TOPPAD-1 | 2 mm solid silicone sheet 60 Shore A nominal; adhesive to metal only; friction not qualified.
B04-107-PRESSPAD--1, B04-107-PRESSPAD-1 | Steel thrust foot directly bears on flat underside; polymer retaining clips carry no clamp load.
B04-108-LOWPAD--1, B04-108-LOWPAD-1 | 2 mm solid silicone sheet; bond to spreader upper face.
B04-109-FOOT-CAGE--1--1, B04-109-FOOT-CAGE--1-1, B04-109-FOOT-CAGE-1--1, B04-109-FOOT-CAGE-1-1 | Split retainer, D28 x8 chamber / D22 throat; 0.4mm split gap. Non-load-bearing. Post-drill screw holes D3.4 +0.2/0. Steel foot D25 flange x6, D18 neck x7 allocation. Verify received part articulation before use.
B04-201-CRADLE-L, B04-201-CRADLE-R | Profile corners R4. Withdraw controller toward +Y; cradle removed without loosening main desk clamp.
B04-202-TRAY | Controller mechanical gauge 180x150x50, max3kg allocation; controller ventilation to be checked separately. Do not install screws within the central controller footprint.
B04-203-STOP-REAR, B04-203-STOP-FRONT | Front stop removable using 2 M4x16; controller gauge slides toward +Y. Use separate adjustable strap through tray side slots to retain vertically.
B04-301-COVER-REAR, B04-301-COVER-FRONT | Nominal wall2.5, roof3.0; clearances checked on nominal geometry. Print as separate front/rear pieces; rear lifts vertically for PCB access; seam0.8mm. Cosmetic shroud carries no arm or clamp load. Post-drill screw holes D3.4 +0.2/0 at assembly jig.

# ODRADEK / 加工特征与全局入口坐标

### 相同标注已成组；全部入口坐标保留 / 本表不含采购包络的伪加工尺寸

manifest SHA256 ad065c979d159c1636a3b4f45636eb2d2e782b9553024c0c5ffa4498b730d9ef

特征 / 属性路径 | 数值、方向和限定说明（长度默认 mm；其他单位以字段名为准）

B04-101-DECK
D8.5 THRU

axis=[0, 0, 1], model_depth_mm=12, model_diameter_mm=8.5 全局入口坐标 XYZ: (-45, 90, 2); (45, 90, 2); (-45, 180, 2); (45, 180, 2)

B04-101-DECK
CBORE D15 x 8.5 FROM BOTTOM axis=[0, 0, 1], model_depth_mm=8.5, model_diameter_mm=15 全局入口坐标 XYZ: (-45, 90, 2); (45, 90, 2); (-45, 180, 2); (45, 180, 2)

B04-101-DECK
M6x1-6H; FULL THREAD >=14; DRILL 17 axis=[1, 0, 0], model_depth_mm=17, model_diameter_mm=5 全局入口坐标 XYZ: (-110, 15, 8); (-110, 45, 8); (-110, 75, 8)

B04-101-DECK
M6x1-6H; FULL THREAD >=14; DRILL 17 axis=[-1, 0, 0], model_depth_mm=17, model_diameter_mm=5 全局入口坐标 XYZ: (110, 15, 8); (110, 45, 8); (110, 75, 8)

B04-101-DECK
D3.4 THRU

axis=[0, 0, 1], model_depth_mm=12, model_diameter_mm=3.4
全局入口坐标 XYZ: (-100, 35, 2); (100, 35, 2); (-100, 75, 2); (100, 75, 2); (-88, 185, 2); (88, 185, 2)

B04-101-DECK
CSK D6.3 x 90 DEG FROM BOTTOM; M3x20 FLAT HEAD

axis=[0, 0, 1]
全局入口坐标 XYZ: (-100, 35, 2); (100, 35, 2); (-100, 75, 2); (100, 75, 2); (-88, 185, 2); (88, 185, 2)

B04-101-DECK
M3x0.5-6H; FULL THREAD 6; DRILL 8 axis=[0, 0, -1], model_depth_mm=8, model_diameter_mm=2.5
全局入口坐标 XYZ: (-35, 3, 14); (35, 3, 14); (35, 43, 14); (-35, 43, 14)

B04-101-DECK
M4x0.7-6H; FULL THREAD 7; CHASSIS BOND LUG axis=[0, 0, -1], model_depth_mm=9, model_diameter_mm=3.3 全局入口坐标 XYZ: (90, -15, 14)

B04-101-DECK
36 x16 THRU WINDOW, R4; X43..79 Y-34..-18; CABLE DROP | 全局入口坐标 XYZ: (61, -26, 2)
B04-102-CPLATE-L D6.6 THRU; M6x25 + WASHER | axis=[1, 0, 0], model_depth_mm=10, model_diameter_mm=6.6
| 全局入口坐标 XYZ: (-120, 15, 8); (-120, 45, 8); (-120, 75, 8)
B04-102-CPLATE-L D8.5 THRU; M8x25 + WASHER | axis=[1, 0, 0], model_depth_mm=10, model_diameter_mm=8.5
| 全局入口坐标 XYZ: (-120, 40, -101); (-120, 75, -101)
B04-102-CPLATE-L M6x1-6H THRU; CRADLE | axis=[1, 0, 0], model_depth_mm=10, model_diameter_mm=5
| 全局入口坐标 XYZ: (-120, -18, -70); (-120, -18, -95)
B04-102-CPLATE-R D6.6 THRU; M6x25 + WASHER | axis=[-1, 0, 0], model_depth_mm=10, model_diameter_mm=6.6
| 全局入口坐标 XYZ: (120, 15, 8); (120, 45, 8); (120, 75, 8)
B04-102-CPLATE-R D8.5 THRU; M8x25 + WASHER | axis=[-1, 0, 0], model_depth_mm=10, model_diameter_mm=8.5
| 全局入口坐标 XYZ: (120, 40, -101); (120, 75, -101)
B04-102-CPLATE-R M6x1-6H THRU; CRADLE | axis=[-1, 0, 0], model_depth_mm=10, model_diameter_mm=5
| 全局入口坐标 XYZ: (120, -18, -70); (120, -18, -95)
B04-103-BRIDGE M12x1.75-6H THRU; BREAK BOTH ENTRIES 0.5 | axis=[0, 0, 1], model_depth_mm=22, model_diameter_mm=10.2
| 全局入口坐标 XYZ: (-85, 55, -112); (85, 55, -112)
B04-103-BRIDGE M8x1.25-6H; FULL THREAD >=15; DRILL 18 | axis=[1, 0, 0], model_depth_mm=18, model_diameter_mm=6.8
| 全局入口坐标 XYZ: (-110, 40, -101); (-110, 75, -101)

manifest SHA256 ad065c979d159c1636a3b4f45636eb2d2e782b9553024c0c5ffa4498b730d9ef

特征 / 属性路径 | 数值、方向和限定说明（长度默认 mm；其他单位以字段名为准）

B04-103-BRIDGE
M8x1.25-6H; FULL THREAD >=15; DRILL 18 axis=[-1, 0, 0], model_depth_mm=18, model_diameter_mm=6.8 全局入口坐标 XYZ: (110, 40, -101); (110, 75, -101)

B04-104-FLANGE
D8.5 THRU; M8x25 + WASHER

axis=[0, 0, 1], model_depth_mm=12, model_diameter_mm=8.5
全局入口坐标 XYZ: (-45, 90, 46); (45, 90, 46); (-45, 180, 46); (45, 180, 46)

B04-104-FLANGE
M6x1-6H THRU; PCD120

axis=[0, 0, 1], model_depth_mm=12, model_diameter_mm=5
全局入口坐标 XYZ: (55.43277, 157.96101, 46); (22.96101, 190.43277, 46); (-22.96101, 190.43277, 46); (-55.43277, 157.96101, 46); (-55.43277, 112.03899, 46); (-22.96101, 79.56723, 46);

(22.96101, 79.56723, 46); (55.43277, 112.03899, 46)

B04-105-POST-1
M8x1.25-6H THRU

axis=[0, 0, 1], model_depth_mm=32, model_diameter_mm=6.8 全局入口坐标 XYZ: (-45, 90, 14)

B04-105-POST-2
M8x1.25-6H THRU

axis=[0, 0, 1], model_depth_mm=32, model_diameter_mm=6.8 全局入口坐标 XYZ: (45, 90, 14)

B04-105-POST-3
M8x1.25-6H THRU

axis=[0, 0, 1], model_depth_mm=32, model_diameter_mm=6.8 全局入口坐标 XYZ: (-45, 180, 14)

B04-105-POST-4
M8x1.25-6H THRU

axis=[0, 0, 1], model_depth_mm=32, model_diameter_mm=6.8 全局入口坐标 XYZ: (45, 180, 14)

B04-107-PRESSPAD--1
M3x0.5-6H; FULL THREAD4; DRILL6; FOOT RETAINER axis=[0, 0, 1], model_depth_mm=6, model_diameter_mm=2.5 全局入口坐标 XYZ: (-108, 55, -40); (-62, 55, -40)

B04-109-FOOT-CAGE--1--1
D3.4 THRU; M3x14, ENGAGEMENT4 axis=[0, 0, 1], model_depth_mm=10, model_diameter_mm=3.4 全局入口坐标 XYZ: (-108, 55, -50)

B04-109-FOOT-CAGE--1-1
D3.4 THRU; M3x14, ENGAGEMENT4 axis=[0, 0, 1], model_depth_mm=10, model_diameter_mm=3.4 全局入口坐标 XYZ: (-62, 55, -50)

B04-107-PRESSPAD-1
M3x0.5-6H; FULL THREAD4; DRILL6; FOOT RETAINER axis=[0, 0, 1], model_depth_mm=6, model_diameter_mm=2.5 全局入口坐标 XYZ: (62, 55, -40); (108, 55, -40)

B04-109-FOOT-CAGE-1--1
D3.4 THRU; M3x14, ENGAGEMENT4 axis=[0, 0, 1], model_depth_mm=10, model_diameter_mm=3.4 全局入口坐标 XYZ: (62, 55, -50)

B04-109-FOOT-CAGE-1-1
D3.4 THRU; M3x14, ENGAGEMENT4 axis=[0, 0, 1], model_depth_mm=10, model_diameter_mm=3.4 全局入口坐标 XYZ: (108, 55, -50)

B04-201-CRADLE-L
D6.6 THRU; M6x20 + WASHER

axis=[1, 0, 0], model_depth_mm=8, model_diameter_mm=6.6 全局入口坐标 XYZ: (-128, -18, -70); (-128, -18, -95)

B04-201-CRADLE-L
M4x0.7-6H; FULL THREAD9; DRILL12 axis=[0, 0, -1], model_depth_mm=12, model_diameter_mm=3.3 全局入口坐标 XYZ: (-124, 140, -175); (-124, 250, -175)

B04-201-CRADLE-R
D6.6 THRU; M6x20 + WASHER

axis=[-1, 0, 0], model_depth_mm=8, model_diameter_mm=6.6 全局入口坐标 XYZ: (128, -18, -70); (128, -18, -95)

manifest SHA256 ad065c979d159c1636a3b4f45636eb2d2e782b9553024c0c5ffa4498b730d9ef

特征 / 属性路径 | 数值、方向和限定说明（长度默认 mm；其他单位以字段名为准）

B04-201-CRADLE-R
M4x0.7-6H; FULL THREAD9; DRILL12 axis=[0, 0, -1], model_depth_mm=12, model_diameter_mm=3.3 全局入口坐标 XYZ: (124, 140, -175); (124, 250, -175)

B04-202-TRAY
D4.5 THRU; M4x12

axis=[0, 0, 1], model_depth_mm=5, model_diameter_mm=4.5
全局入口坐标 XYZ: (-124, 140, -175); (-124, 250, -175); (124, 140, -175); (124, 250, -175)

B04-202-TRAY
M4x0.7-6H THRU; STOP M4x16 axis=[0, 0, 1], model_depth_mm=5, model_diameter_mm=3.3
全局入口坐标 XYZ: (-100, 112, -175); (100, 112, -175); (-100, 278, -175); (100, 278, -175)

B04-202-TRAY
4 x24 THRU SLOT, R1.5; 20mm RETAINING STRAP | 全局入口坐标 XYZ: (-108, 187, -175); (108, 187, -175)
B04-203-STOP-REAR D4.5 THRU; M4x16 | axis=[0, 0, 1], model_depth_mm=12, model_diameter_mm=4.5
| 全局入口坐标 XYZ: (-100, 112, -170); (100, 112, -170)
B04-203-STOP-FRONT D4.5 THRU; M4x16 | axis=[0, 0, 1], model_depth_mm=12, model_diameter_mm=4.5
| 全局入口坐标 XYZ: (-100, 278, -170); (100, 278, -170)
B04-301-COVER-REAR D3.4 THRU; M3x8 + WASHER | axis=[0, 0, 1], model_depth_mm=3, model_diameter_mm=3.4
| 全局入口坐标 XYZ: (-100, 35, 49); (100, 35, 49)
B04-301-COVER-FRONT D3.4 THRU; M3x8 + WASHER | axis=[0, 0, 1], model_depth_mm=3, model_diameter_mm=3.4
| 全局入口坐标 XYZ: (-100, 75, 49); (100, 75, 49); (-88, 185, 49); (88, 185, 49)

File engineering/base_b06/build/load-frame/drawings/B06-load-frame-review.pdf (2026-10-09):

## AUROMIX / ODRADEK | B06-LOAD-03-WELD

## B06-101-LOAD-DECK

REVIEW CANDIDATE - NOT COMPLETE BASE MANUFACTURING RELEASE
Units mm. Do not scale drawing. Exact STEP profile governs. Sheet 1/15
TOP XY - fitted view (NTS) | FRONT XZ - fitted view (NTS) | SIDE YZ - fitted view (NTS)

ENVELOPE / GLOBAL ASSEMBLY DATUM

X [-70.000, 70.000] Y [-59.000, 151.000] Z [2.000, 17.000]

Overall 140.000 x 210.000 x 15.000; material S355; exact STEP: B06-101-LOAD-DECK.step

Assembly origin: X0 centreline; Y75 arm axis; Z0 tabletop. Ordinate features below use these datums.

Metal general linear +/-0.10; hole centres +/-0.10; cut silicone +/-0.50; threads as called out; deburr R0.5.

CNC profile and drill/counterbore; weld assembly B06-W01
15 mm finished thickness; rear Y-59, table rear edge Y-45; corners deburr R0.5
Datum A upper Z17; flatness0.15 after welding; no polymer carries arm preload
FEATURES: entry X/Y/Z ; axis ; bore/depth ; machining callout

0.000/75.000/2.000 ; [0/0/1] ; D56.000 x 15.000 ; D56 THRU; harness passage
-60.000/75.000/2.000 ; [0/0/1] ; D8.500 x 15.000 ; D8.5 THRU
-60.000/75.000/2.000 ; [0/0/1] ; D14.500 x 8.500 ; BOTTOM CBORE D14.5 x8.5; M8x20 ISO4762; underhead Z10.5 60.000/75.000/2.000 ; [0/0/1] ; D8.500 x 15.000 ; D8.5 THRU
60.000/75.000/2.000 ; [0/0/1] ; D14.500 x 8.500 ; BOTTOM CBORE D14.5 x8.5; M8x20 ISO4762; underhead Z10.5 -38.000/120.000/2.000 ; [0/0/1] ; D8.500 x 15.000 ; D8.5 THRU
-38.000/120.000/2.000 ; [0/0/1] ; D14.500 x 8.500 ; BOTTOM CBORE D14.5 x8.5; M8x20 ISO4762; underhead Z10.5 38.000/120.000/2.000 ; [0/0/1] ; D8.500 x 15.000 ; D8.5 THRU
38.000/120.000/2.000 ; [0/0/1] ; D14.500 x 8.500 ; BOTTOM CBORE D14.5 x8.5; M8x20 ISO4762; underhead Z10.5 -52.000/-20.000/2.000 ; [0/0/1] ; D3.600 x 15.000 ; D3.6 THRU; clearance for PCB screw tip, no electrical board contact -52.000/24.000/2.000 ; [0/0/1] ; D3.600 x 15.000 ; D3.6 THRU; clearance for PCB screw tip, no electrical board contact 52.000/-20.000/2.000 ; [0/0/1] ; D3.600 x 15.000 ; D3.6 THRU; clearance for PCB screw tip, no electrical board contact 52.000/24.000/2.000 ; [0/0/1] ; D3.600 x 15.000 ; D3.6 THRU; clearance for PCB screw tip, no electrical board contact 62.000/15.000/17.000 ; [0/0/-1] ; D5.000 x 12.000 ; M6x1-6H; full thread9; drill12; dedicated chassis bonding point

## B06-102-REAR-WEB

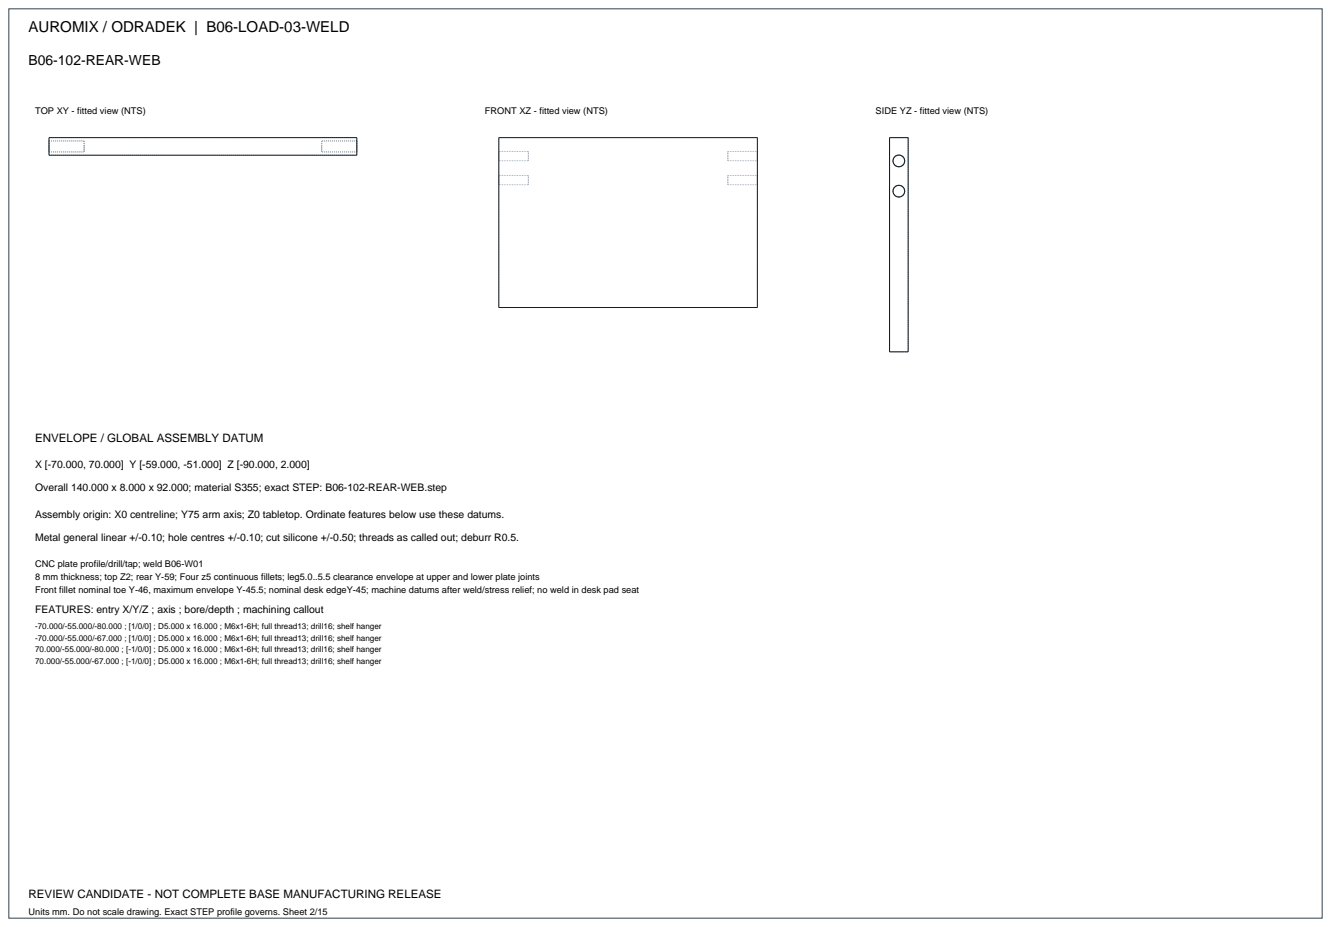
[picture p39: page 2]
TOP XY - fitted view (NTS); FRONT XZ - fitted view (NTS); SIDE YZ - fitted view (NTS)

ENVELOPE / GLOBAL ASSEMBLY DATUM

Overall 140.000 x 8.000 x 92.000; material S355; exact STEP: B06-102-REAR-WEB.step

Assembly origin: X0 centreline; Y75 arm axis; Z0 tabletop. Ordinate features below use these datums.
Metal general linear +/-0.10; hole centres +/-0.10; cut silicone +/-0.50; threads as called out; deburr R0.5.

CNC plate profile/drill/tap; weld B06-W01
8 mm thickness; top Z2; rear Y-59; Four z5 continuous fillets; leg5.0..5.5 clearance envelope at upper and lower plate joints
Front fillet nominal toe Y-46, maximum envelope Y-45.5; nominal desk edgeY-45; machine datums after weld/stress relief; no weld in desk pad seat
FEATURES: entry X/Y/Z ; axis ; bore/depth ; machining callout

-70.000/-55.000/-80.000 ; [1/0/0] ; D5.000 x 16.000 ; M6x1-6H; full thread13; drill16; shelf hanger
-70.000/-55.000/-67.000 ; [1/0/0] ; D5.000 x 16.000 ; M6x1-6H; full thread13; drill16; shelf hanger
70.000/-55.000/-80.000 ; [-1/0/0] ; D5.000 x 16.000 ; M6x1-6H; full thread13; drill16; shelf hanger
70.000/-55.000/-67.000 ; [-1/0/0] ; D5.000 x 16.000 ; M6x1-6H; full thread13; drill16; shelf hanger

Units mm. Do not scale drawing. Exact STEP profile governs. Sheet 2/15

## B06-103-LOWER-JAW

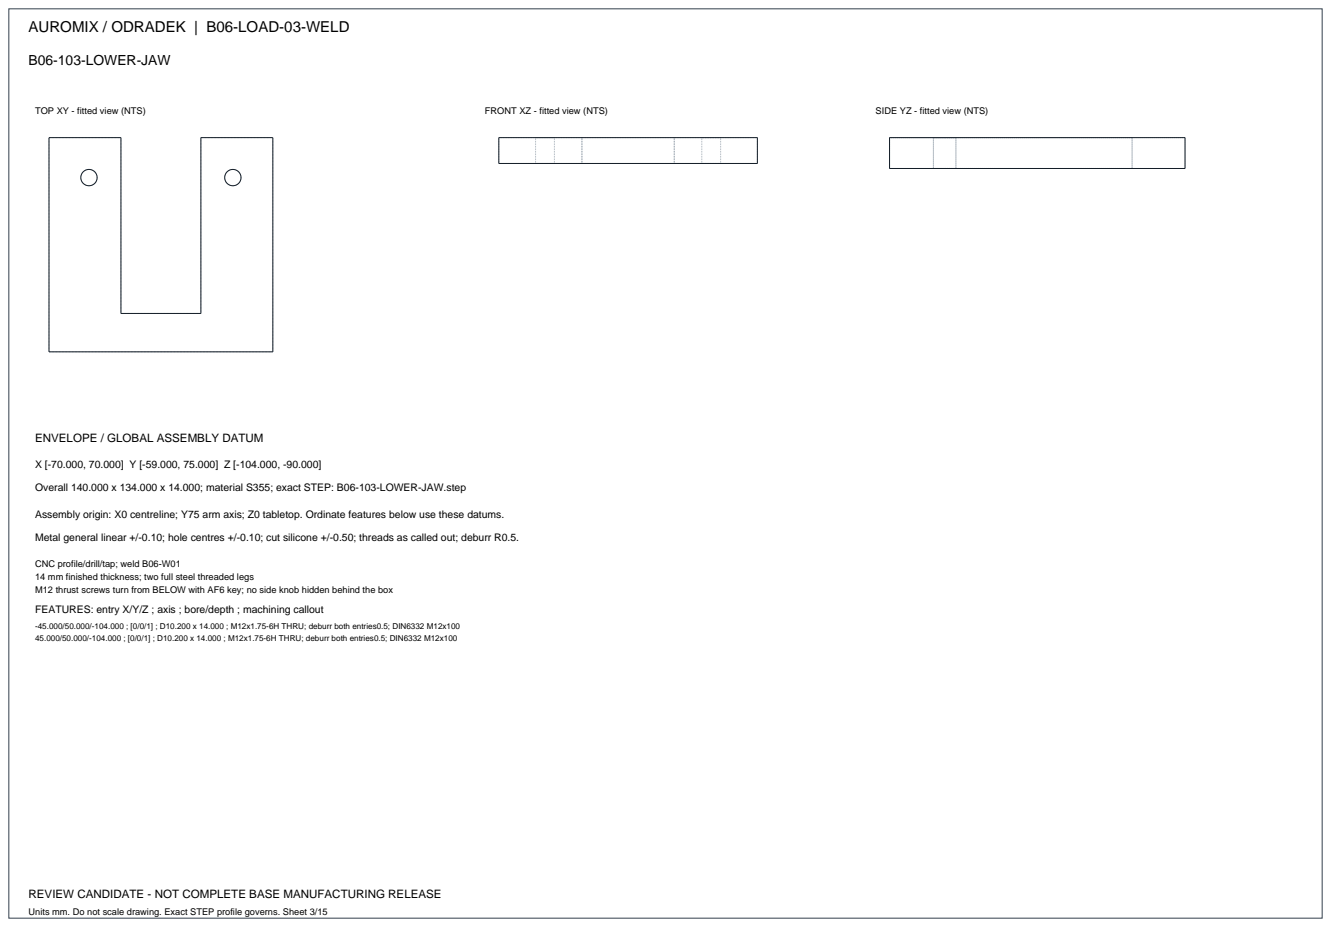
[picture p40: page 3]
TOP XY - fitted view (NTS); FRONT XZ - fitted view (NTS); SIDE YZ - fitted view (NTS)

ENVELOPE / GLOBAL ASSEMBLY DATUM

Overall 140.000 x 134.000 x 14.000; material S355; exact STEP: B06-103-LOWER-JAW.step

Assembly origin: X0 centreline; Y75 arm axis; Z0 tabletop. Ordinate features below use these datums.
Metal general linear +/-0.10; hole centres +/-0.10; cut silicone +/-0.50; threads as called out; deburr R0.5.

CNC profile/drill/tap; weld B06-W01
14 mm finished thickness; two full steel threaded legs
M12 thrust screws turn from BELOW with AF6 key; no side knob hidden behind the box
FEATURES: entry X/Y/Z ; axis ; bore/depth ; machining callout

-45.000/50.000/-104.000 ; [0/0/1] ; D10.200 x 14.000 ; M12x1.75-6H THRU; deburr both entries0.5; DIN6332 M12x100
45.000/50.000/-104.000 ; [0/0/1] ; D10.200 x 14.000 ; M12x1.75-6H THRU; deburr both entries0.5; DIN6332 M12x100

Units mm. Do not scale drawing. Exact STEP profile governs. Sheet 3/15

## B06-104-LOAD-FLANGE

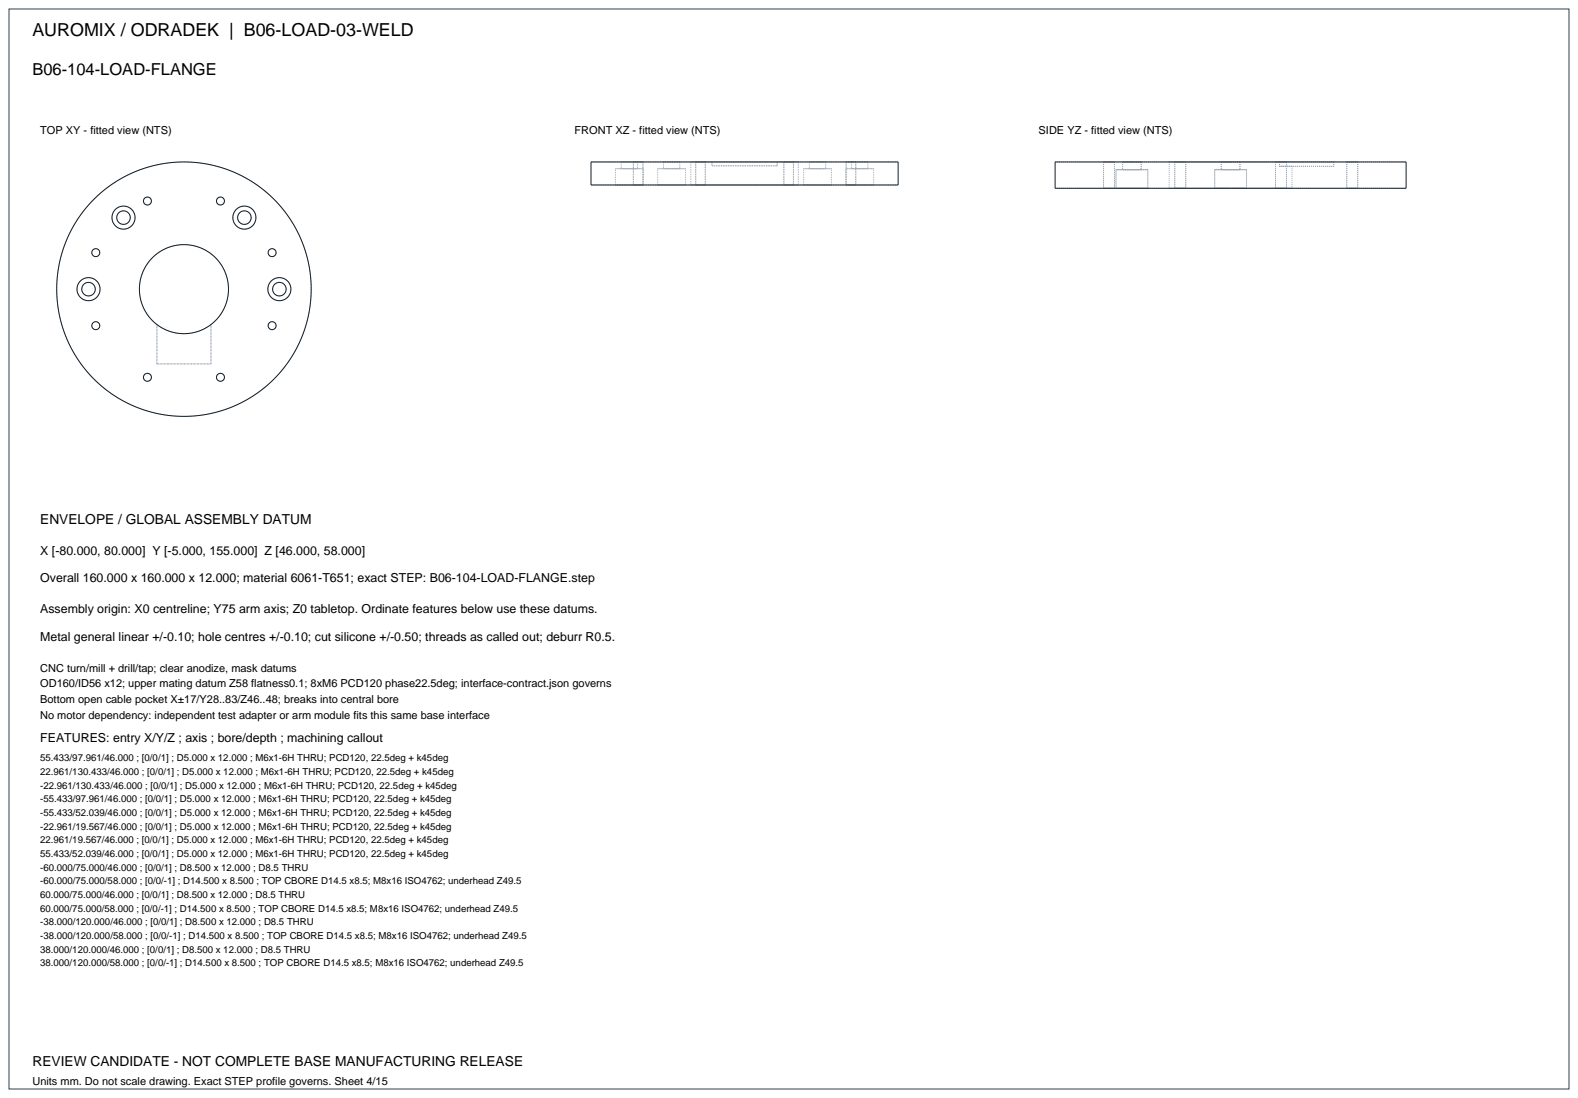
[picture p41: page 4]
TOP XY - fitted view (NTS); FRONT XZ - fitted view (NTS); SIDE YZ - fitted view (NTS)

ENVELOPE / GLOBAL ASSEMBLY DATUM

Overall 160.000 x 160.000 x 12.000; material 6061-T651; exact STEP: B06-104-LOAD-FLANGE.step

Assembly origin: X0 centreline; Y75 arm axis; Z0 tabletop. Ordinate features below use these datums.
Metal general linear +/-0.10; hole centres +/-0.10; cut silicone +/-0.50; threads as called out; deburr R0.5.

CNC turn/mill + drill/tap; clear anodize, mask datums
OD160/ID56 x12; upper mating datum Z58 flatness0.1; 8xM6 PCD120 phase22.5deg; interface-contract.json governs
Bottom open cable pocket X±17/Y28..83/Z46..48; breaks into central bore
No motor dependency: independent test adapter or arm module fits this same base interface
FEATURES: entry X/Y/Z ; axis ; bore/depth ; machining callout

55.433/97.961/46.000 ; [0/0/1] ; D5.000 x 12.000 ; M6x1-6H THRU; PCD120, 22.5deg + k45deg
22.961/130.433/46.000 ; [0/0/1] ; D5.000 x 12.000 ; M6x1-6H THRU; PCD120, 22.5deg + k45deg
-22.961/130.433/46.000 ; [0/0/1] ; D5.000 x 12.000 ; M6x1-6H THRU; PCD120, 22.5deg + k45deg
-55.433/97.961/46.000 ; [0/0/1] ; D5.000 x 12.000 ; M6x1-6H THRU; PCD120, 22.5deg + k45deg
-55.433/52.039/46.000 ; [0/0/1] ; D5.000 x 12.000 ; M6x1-6H THRU; PCD120, 22.5deg + k45deg
-22.961/19.567/46.000 ; [0/0/1] ; D5.000 x 12.000 ; M6x1-6H THRU; PCD120, 22.5deg + k45deg
22.961/19.567/46.000 ; [0/0/1] ; D5.000 x 12.000 ; M6x1-6H THRU; PCD120, 22.5deg + k45deg
55.433/52.039/46.000 ; [0/0/1] ; D5.000 x 12.000 ; M6x1-6H THRU; PCD120, 22.5deg + k45deg
-60.000/75.000/46.000 ; [0/0/1] ; D8.500 x 12.000 ; D8.5 THRU
-60.000/75.000/58.000 ; [0/0/-1] ; D14.500 x 8.500 ; TOP CBORE D14.5 x8.5; M8x16 ISO4762; underhead Z49.5
60.000/75.000/46.000 ; [0/0/1] ; D8.500 x 12.000 ; D8.5 THRU
60.000/75.000/58.000 ; [0/0/-1] ; D14.500 x 8.500 ; TOP CBORE D14.5 x8.5; M8x16 ISO4762; underhead Z49.5
-38.000/120.000/46.000 ; [0/0/1] ; D8.500 x 12.000 ; D8.5 THRU
-38.000/120.000/58.000 ; [0/0/-1] ; D14.500 x 8.500 ; TOP CBORE D14.5 x8.5; M8x16 ISO4762; underhead Z49.5
38.000/120.000/46.000 ; [0/0/1] ; D8.500 x 12.000 ; D8.5 THRU
38.000/120.000/58.000 ; [0/0/-1] ; D14.500 x 8.500 ; TOP CBORE D14.5 x8.5; M8x16 ISO4762; underhead Z49.5

Units mm. Do not scale drawing. Exact STEP profile governs. Sheet 4/15

## B06-105-POST-1

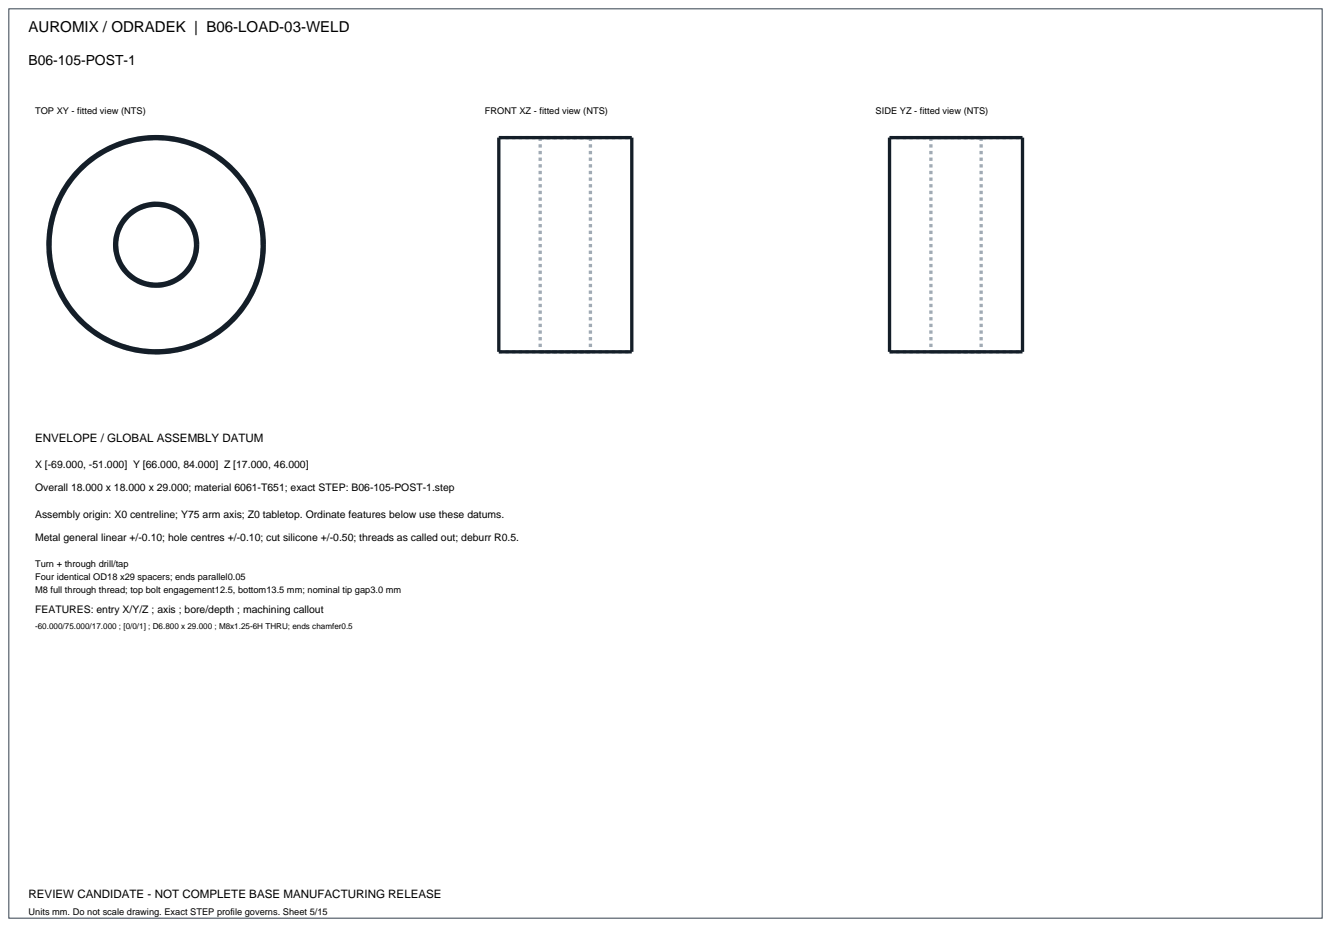
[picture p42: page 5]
TOP XY - fitted view (NTS); FRONT XZ - fitted view (NTS); SIDE YZ - fitted view (NTS); -60.000/75.000/17.000 ; [0/0/1] ; D6.800 x 29.000 ; M8x1.25-6H THRU; ends chamfer0.5

ENVELOPE / GLOBAL ASSEMBLY DATUM

Overall 18.000 x 18.000 x 29.000; material 6061-T651; exact STEP: B06-105-POST-1.step

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

Turn + through drill/tap
Four identical OD18 x29 spacers; ends parallel0.05
M8 full through thread; top bolt engagement12.5, bottom13.5 mm; nominal tip gap3.0 mm
FEATURES: entry X/Y/Z ; axis ; bore/depth ; machining callout

Units mm. Do not scale drawing. Exact STEP profile governs. Sheet 5/15

## B06-106-DESK-PAD

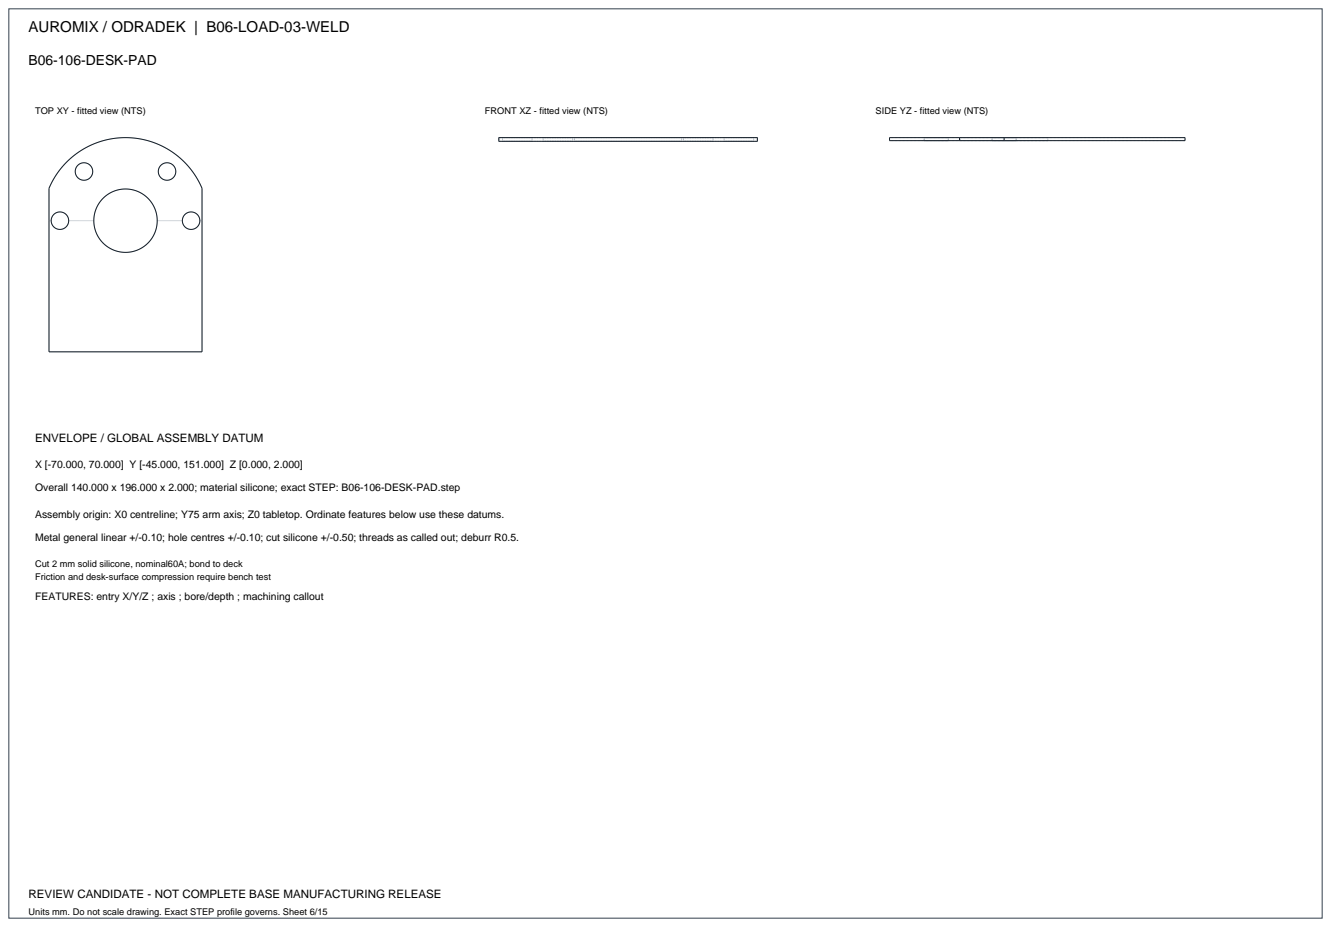
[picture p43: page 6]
TOP XY - fitted view (NTS); FRONT XZ - fitted view (NTS); SIDE YZ - fitted view (NTS)

ENVELOPE / GLOBAL ASSEMBLY DATUM

Overall 140.000 x 196.000 x 2.000; material silicone; exact STEP: B06-106-DESK-PAD.step

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

Cut 2 mm solid silicone, nominal60A; bond to deck
Friction and desk-surface compression require bench test
FEATURES: entry X/Y/Z ; axis ; bore/depth ; machining callout

Units mm. Do not scale drawing. Exact STEP profile governs. Sheet 6/15

## B06-107-SPREADER-1

Units mm. Do not scale drawing. Exact STEP profile governs. Sheet 7/15

TOP XY - fitted view (NTS) | FRONT XZ - fitted view (NTS) | SIDE YZ - fitted view (NTS)

ENVELOPE / GLOBAL ASSEMBLY DATUM

X [10.000, 80.000] Y [5.000, 95.000] Z [-40.000, -32.000]

Overall 70.000 x 90.000 x 8.000; material 6061-T651; exact STEP: B06-107-SPREADER-1.step

Assembly origin: X0 centreline; Y75 arm axis; Z0 tabletop. Ordinate features below use these datums.

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

CNC flat plate; R2 edge breaks
Foot bears directly on metal at (X±45,Y50); swivel foot retained by its supplied retaining spring
Place spreader during installation; pad must cover the entire contact footprint
FEATURES: entry X/Y/Z ; axis ; bore/depth ; machining callout

## B06-108-PRESS-PAD-1

Units mm. Do not scale drawing. Exact STEP profile governs. Sheet 8/15

TOP XY - fitted view (NTS) | FRONT XZ - fitted view (NTS) | SIDE YZ - fitted view (NTS)

ENVELOPE / GLOBAL ASSEMBLY DATUM

X [10.000, 80.000] Y [5.000, 95.000] Z [-32.000, -30.000]

Overall 70.000 x 90.000 x 2.000; material silicone; exact STEP: B06-108-PRESS-PAD-1.step

Assembly origin: X0 centreline; Y75 arm axis; Z0 tabletop. Ordinate features below use these datums.

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

Cut 2 mm solid silicone60A; bond to spreader
FEATURES: entry X/Y/Z ; axis ; bore/depth ; machining callout

## B06-201-HANGER--1

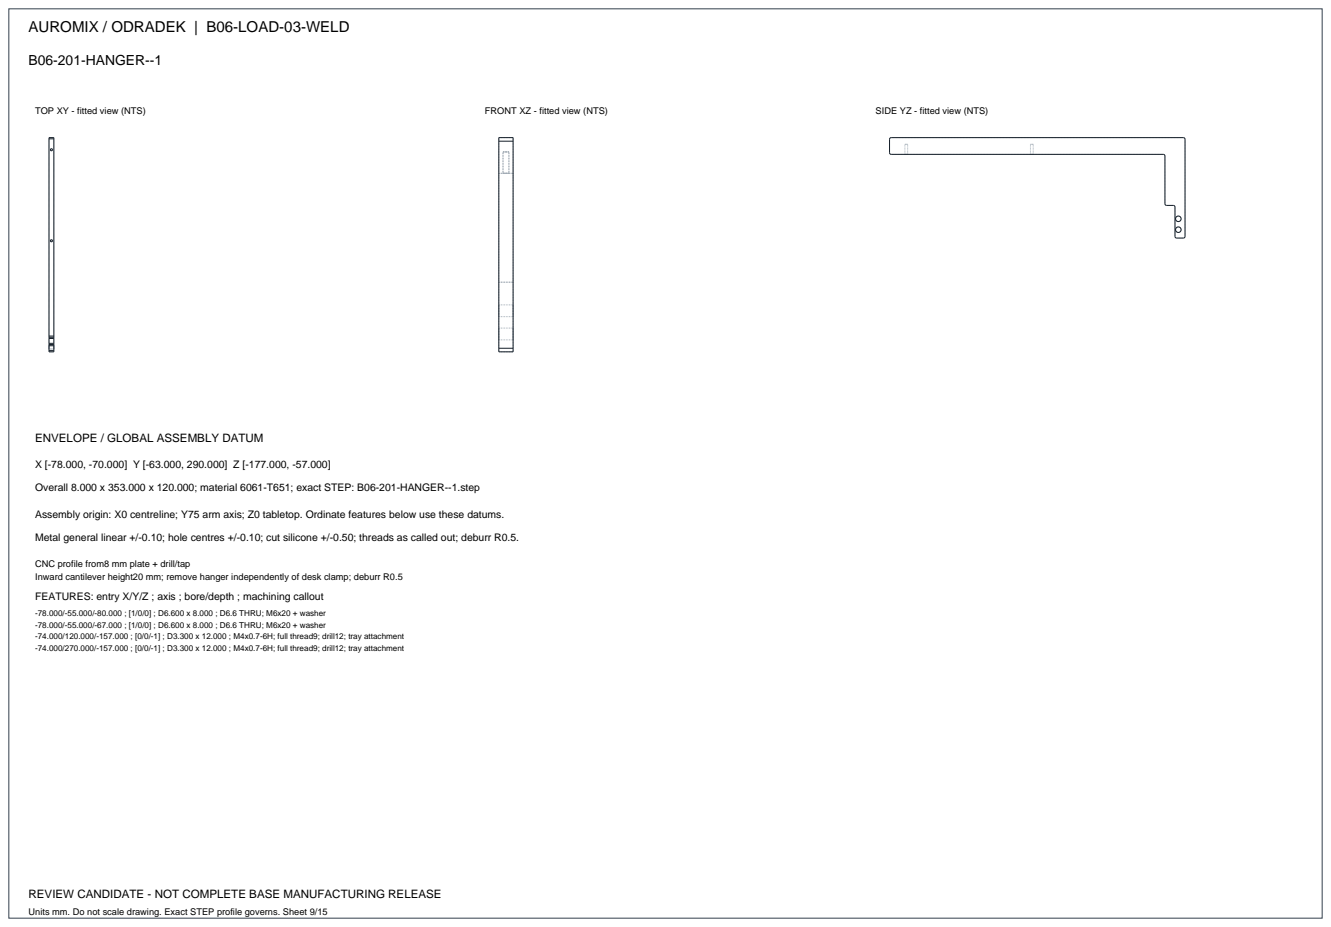
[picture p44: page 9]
TOP XY - fitted view (NTS); FRONT XZ - fitted view (NTS); SIDE YZ - fitted view (NTS)

ENVELOPE / GLOBAL ASSEMBLY DATUM

Overall 8.000 x 353.000 x 120.000; material 6061-T651; exact STEP: B06-201-HANGER--1.step

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

CNC profile from8 mm plate + drill/tap
Inward cantilever height20 mm; remove hanger independently of desk clamp; deburr R0.5
FEATURES: entry X/Y/Z ; axis ; bore/depth ; machining callout

-78.000/-55.000/-80.000 ; [1/0/0] ; D6.600 x 8.000 ; D6.6 THRU; M6x20 + washer
-78.000/-55.000/-67.000 ; [1/0/0] ; D6.600 x 8.000 ; D6.6 THRU; M6x20 + washer
-74.000/120.000/-157.000 ; [0/0/-1] ; D3.300 x 12.000 ; M4x0.7-6H; full thread9; drill12; tray attachment
-74.000/270.000/-157.000 ; [0/0/-1] ; D3.300 x 12.000 ; M4x0.7-6H; full thread9; drill12; tray attachment

Units mm. Do not scale drawing. Exact STEP profile governs. Sheet 9/15

## B06-201-HANGER-1

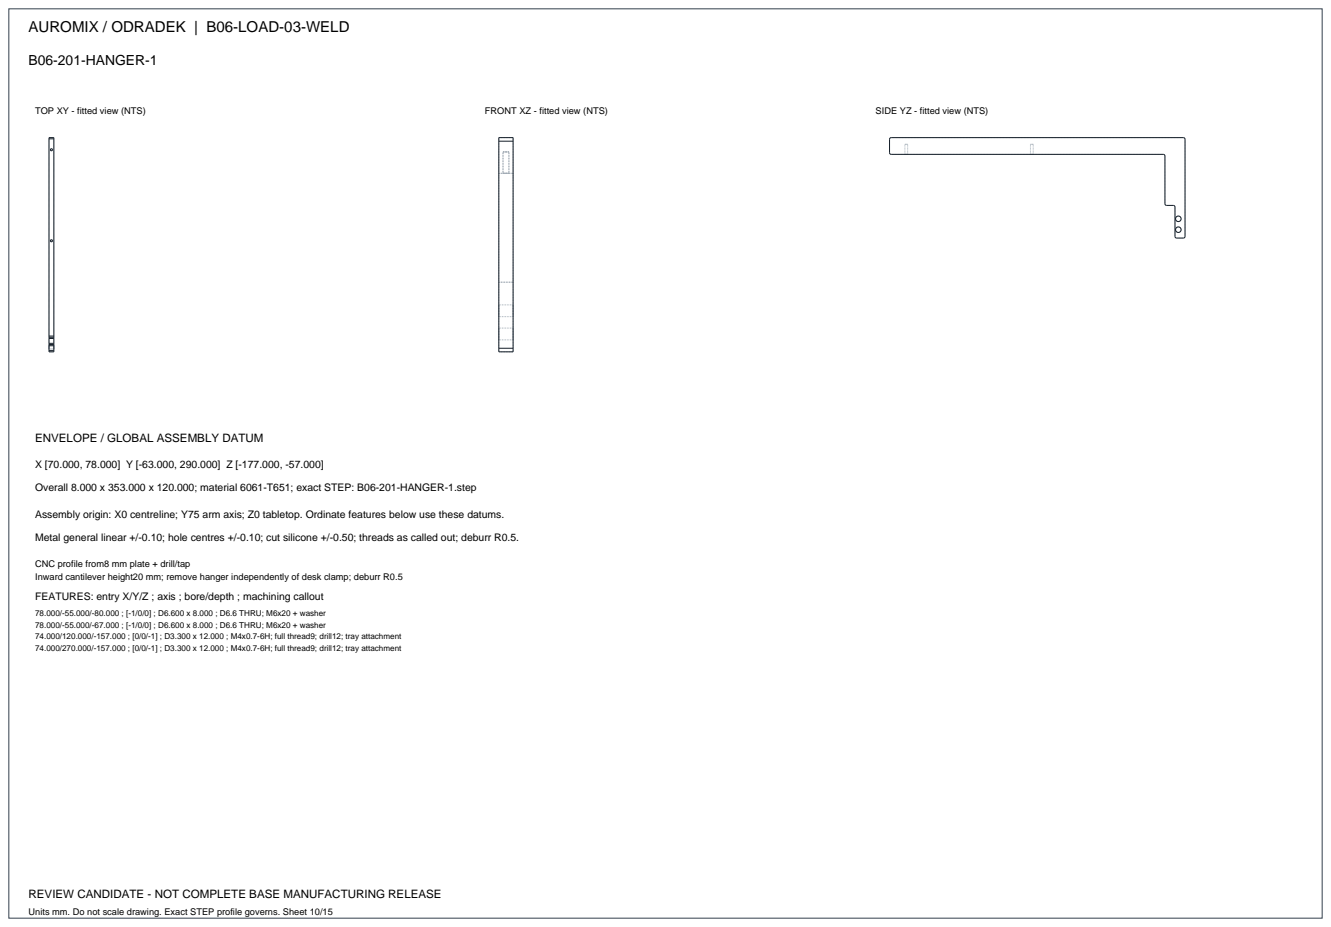
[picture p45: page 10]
TOP XY - fitted view (NTS); FRONT XZ - fitted view (NTS); SIDE YZ - fitted view (NTS)

ENVELOPE / GLOBAL ASSEMBLY DATUM

Overall 8.000 x 353.000 x 120.000; material 6061-T651; exact STEP: B06-201-HANGER-1.step

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

CNC profile from8 mm plate + drill/tap
Inward cantilever height20 mm; remove hanger independently of desk clamp; deburr R0.5
FEATURES: entry X/Y/Z ; axis ; bore/depth ; machining callout

78.000/-55.000/-80.000 ; [-1/0/0] ; D6.600 x 8.000 ; D6.6 THRU; M6x20 + washer
78.000/-55.000/-67.000 ; [-1/0/0] ; D6.600 x 8.000 ; D6.6 THRU; M6x20 + washer
74.000/120.000/-157.000 ; [0/0/-1] ; D3.300 x 12.000 ; M4x0.7-6H; full thread9; drill12; tray attachment
74.000/270.000/-157.000 ; [0/0/-1] ; D3.300 x 12.000 ; M4x0.7-6H; full thread9; drill12; tray attachment

Units mm. Do not scale drawing. Exact STEP profile governs. Sheet 10/15

## B06-202-TRAY

Units mm. Do not scale drawing. Exact STEP profile governs. Sheet 11/15

TOP XY - fitted view (NTS) | FRONT XZ - fitted view (NTS) | SIDE YZ - fitted view (NTS)

ENVELOPE / GLOBAL ASSEMBLY DATUM

X [-100.000, 100.000] Y [100.000, 290.000] Z [-157.000, -152.000]

Overall 200.000 x 190.000 x 5.000; material 6061-T651; exact STEP: B06-202-TRAY.step

Assembly origin: X0 centreline; Y75 arm axis; Z0 tabletop. Ordinate features below use these datums.

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

CNC profile + drill/tap
Confirmed maximum box180x150x50 mm/3 kg; footprint X±90,Y120..270; slides +Y
20 mm hook/loop straps secure vertically; front stop removable; ventilation not covered by this mechanical budget FEATURES: entry X/Y/Z ; axis ; bore/depth ; machining callout

-74.000/120.000/-157.000 ; [0/0/1] ; D4.500 x 5.000 ; D4.5 THRU; M4x10 ISO7380-1; NO washer
-74.000/120.000/-152.000 ; [0/0/-1] ; D8.400 x 3.000 ; TOP CBORE D8.4 x3; head top Z-152.8 below box seat; floor2 mm -74.000/270.000/-157.000 ; [0/0/1] ; D4.500 x 5.000 ; D4.5 THRU; M4x10 ISO7380-1; NO washer -74.000/270.000/-152.000 ; [0/0/-1] ; D8.400 x 3.000 ; TOP CBORE D8.4 x3; head top Z-152.8 below box seat; floor2 mm 74.000/120.000/-157.000 ; [0/0/1] ; D4.500 x 5.000 ; D4.5 THRU; M4x10 ISO7380-1; NO washer 74.000/120.000/-152.000 ; [0/0/-1] ; D8.400 x 3.000 ; TOP CBORE D8.4 x3; head top Z-152.8 below box seat; floor2 mm 74.000/270.000/-157.000 ; [0/0/1] ; D4.500 x 5.000 ; D4.5 THRU; M4x10 ISO7380-1; NO washer 74.000/270.000/-152.000 ; [0/0/-1] ; D8.400 x 3.000 ; TOP CBORE D8.4 x3; head top Z-152.8 below box seat; floor2 mm -96.000/197.000/-157.000 ; [] ; profile slot ; 4x24 vertical strap slot R2 THRU
96.000/197.000/-157.000 ; [] ; profile slot ; 4x24 vertical strap slot R2 THRU
-88.000/112.500/-157.000 ; [0/0/1] ; D3.300 x 5.000 ; M4x0.7-6H THRU; stop M4x20
88.000/112.500/-157.000 ; [0/0/1] ; D3.300 x 5.000 ; M4x0.7-6H THRU; stop M4x20 -88.000/282.500/-157.000 ; [0/0/1] ; D3.300 x 5.000 ; M4x0.7-6H THRU; stop M4x20 88.000/282.500/-157.000 ; [0/0/1] ; D3.300 x 5.000 ; M4x0.7-6H THRU; stop M4x20

## B06-203-STOP-BACK

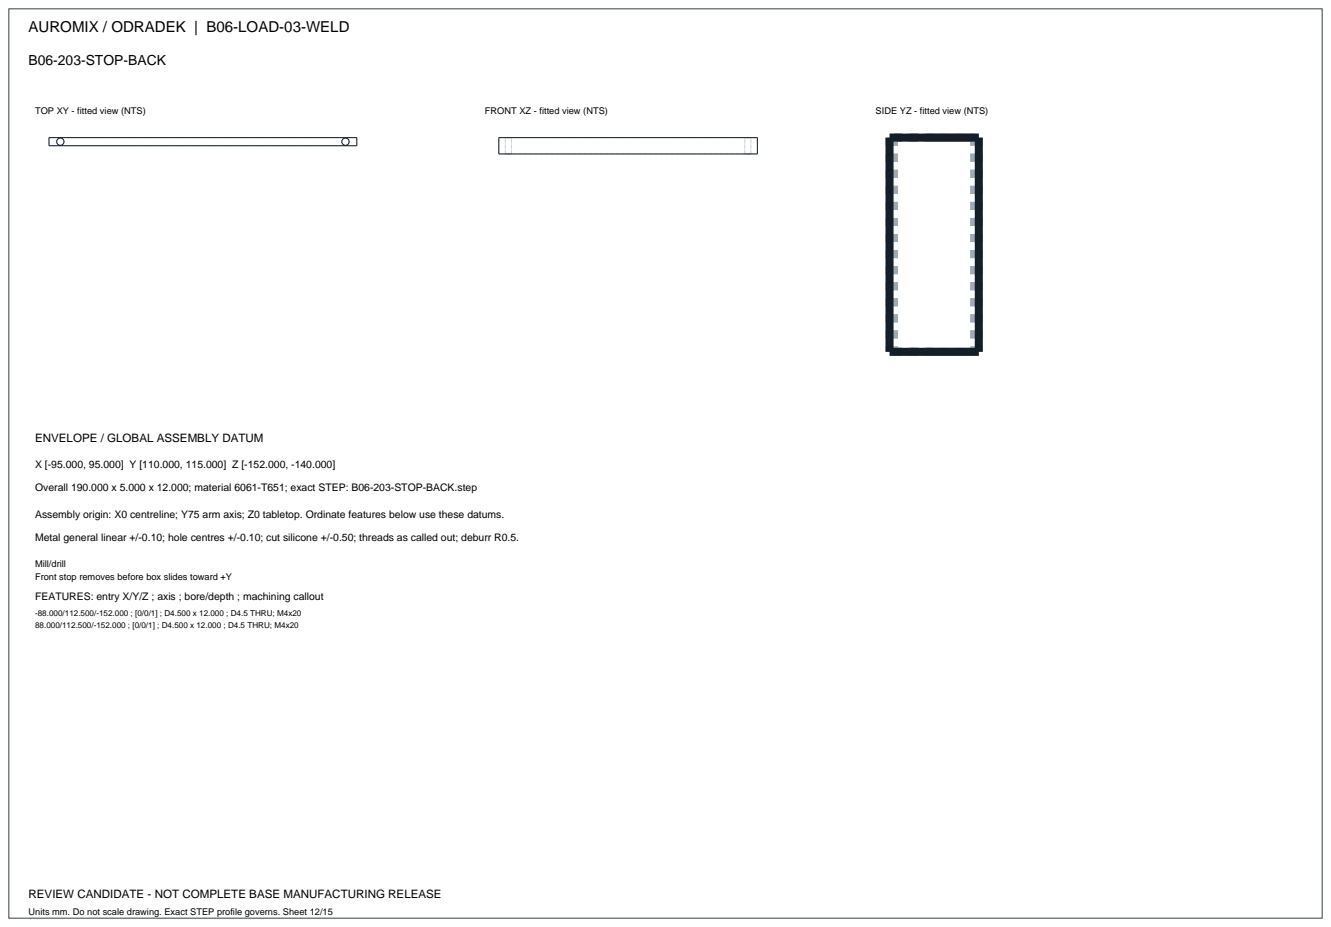
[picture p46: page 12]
TOP XY - fitted view (NTS); FRONT XZ - fitted view (NTS); SIDE YZ - fitted view (NTS); -88.000/112.500/-152.000 ; [0/0/1] ; D4.500 x 12.000 ; D4.5 THRU; M4x20 88.000/112.500/-152.000 ; [0/0/1] ; D4.500 x 12.000 ; D4.5 THRU; M4x20

ENVELOPE / GLOBAL ASSEMBLY DATUM

Overall 190.000 x 5.000 x 12.000; material 6061-T651; exact STEP: B06-203-STOP-BACK.step

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

Mill/drill
Front stop removes before box slides toward +Y
FEATURES: entry X/Y/Z ; axis ; bore/depth ; machining callout

Units mm. Do not scale drawing. Exact STEP profile governs. Sheet 12/15

## B06-203-STOP-FRONT

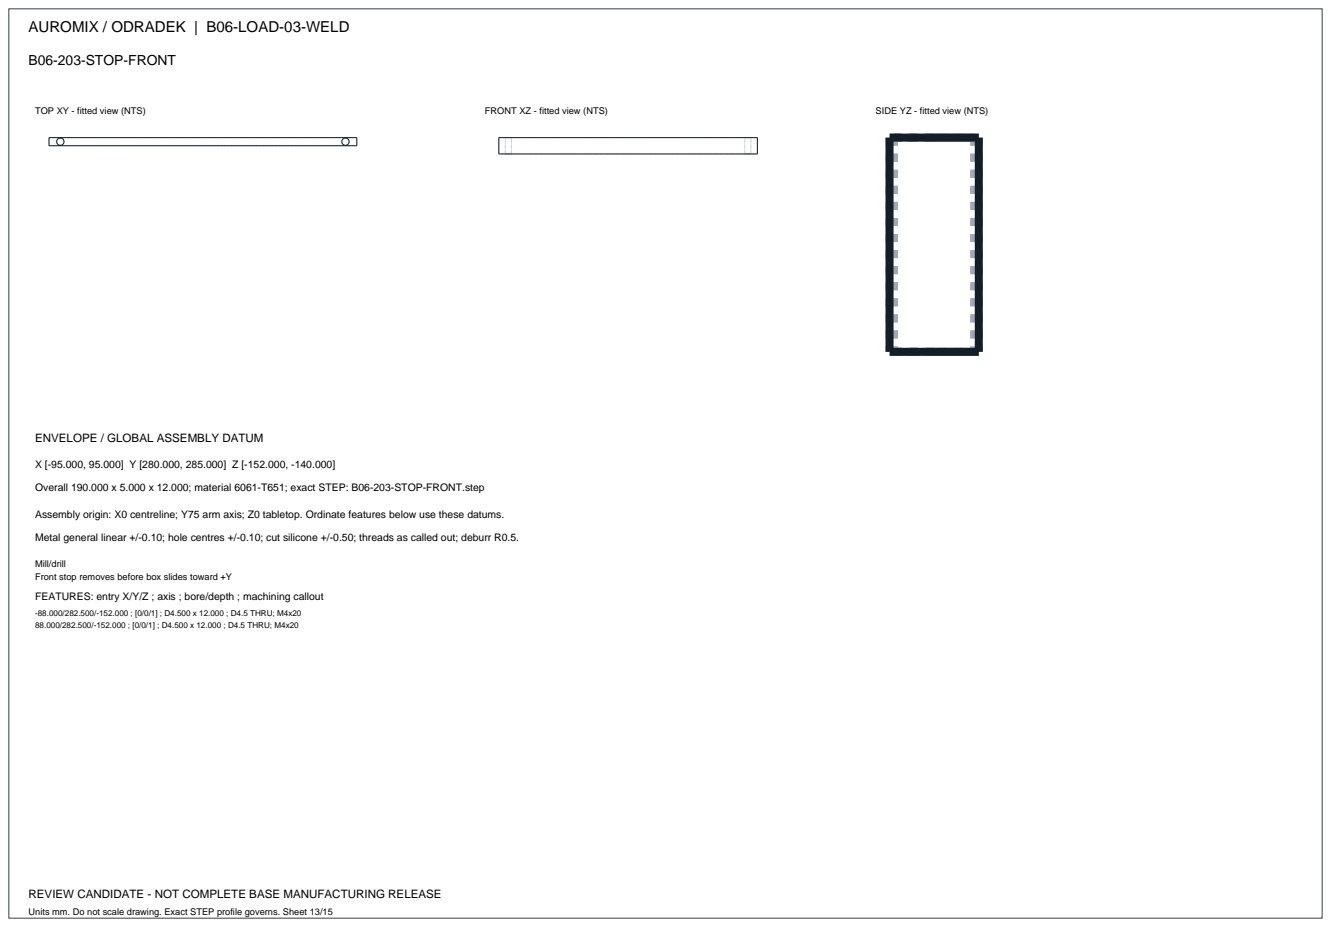
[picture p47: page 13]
TOP XY - fitted view (NTS); FRONT XZ - fitted view (NTS); SIDE YZ - fitted view (NTS); -88.000/282.500/-152.000 ; [0/0/1] ; D4.500 x 12.000 ; D4.5 THRU; M4x20 88.000/282.500/-152.000 ; [0/0/1] ; D4.500 x 12.000 ; D4.5 THRU; M4x20

ENVELOPE / GLOBAL ASSEMBLY DATUM

Overall 190.000 x 5.000 x 12.000; material 6061-T651; exact STEP: B06-203-STOP-FRONT.step

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

Mill/drill
Front stop removes before box slides toward +Y
FEATURES: entry X/Y/Z ; axis ; bore/depth ; machining callout

Units mm. Do not scale drawing. Exact STEP profile governs. Sheet 13/15

## B06-309-COAX-BRACKET

Units mm. Do not scale drawing. Exact STEP profile governs. Sheet 14/15

TOP XY - fitted view (NTS) | FRONT XZ - fitted view (NTS) | SIDE YZ - fitted view (NTS)

ENVELOPE / GLOBAL ASSEMBLY DATUM

X [-20.000, 20.000] Y [-19.000, 0.000] Z [25.600, 42.000]

Overall 40.000 x 19.000 x 16.400; material 6061-T651; exact STEP: B06-309-COAX-BRACKET.step

Assembly origin: X0 centreline; Y75 arm axis; Z0 tabletop. Ordinate features below use these datums.

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

CNC mill original RF bulkhead bracket
Base2 mm at PCB top Z25.6; rear panel4.5 mm Y-19..-14.5; flange bearing face Y-16, internal fillet R1
H5/H6 mounting centres X±10,Y-8; coax axes X±10,Z35; mounts independent of cosmetic rear lid
Fixed coax rear datum retained at Y-16, separate from RJ45/power PCB shift; bond to chassis via J6 lug FEATURES: entry X/Y/Z ; axis ; bore/depth ; machining callout

-10.000/-8.000/25.600 ; [0/0/1] ; D3.600 x 2.000 ; D3.6 THRU; M3x8 + washer0.5 + nut below PCB
-10.000/-19.000/35.000 ; [0/1/0] ; D6.800 x 4.500 ; D6.8 round THRU; external flange captured in hex pocket
-10.000/-19.000/35.000 ; [0/1/0] ; D9.800 x 3.000 ; AF9.8 rear HEX pocket depth3, six R1.05 corner reliefs; flange seat Y-16; source nominal AF9.5 10.000/-8.000/25.600 ; [0/0/1] ; D3.600 x 2.000 ; D3.6 THRU; M3x8 + washer0.5 + nut below PCB
10.000/-19.000/35.000 ; [0/1/0] ; D6.800 x 4.500 ; D6.8 round THRU; external flange captured in hex pocket
10.000/-19.000/35.000 ; [0/1/0] ; D9.800 x 3.000 ; AF9.8 rear HEX pocket depth3, six R1.05 corner reliefs; flange seat Y-16; source nominal AF9.5

## W01 WELDMENT / PURCHASED HARDWARE / RELEASE GATES

Units mm. Do not scale drawing. Exact STEP profile governs. Sheet 15/15

W01 consists of B06-101 deck, B06-102 rear web, B06-103 lower jaw; STEP assembly gives nominal position.

Web top Z2 touches deck bottom Z2; web bottom Z-90 touches jaw top Z-90. NO overlapping plates.

Four continuous steel fillets z5 (nominal throat3.54), leg5.0..5.5, flat/concave profile within maximum modeled envelope.

Do not weld desk pad face, clamp threaded bores or shelf tapped holes. Front toe nominalY-46 / maximumY-45.5; tabletop rear datumY-45.

Nominal weld beads are separate CAD seam solids, not machined parts. Maximum5.5 envelope clearance checked; WPS remains pending.

Fixture assembly; weld sequence/stress relief agreed with fabricator; machine designated datums after weld.

Bought clamp screws: 2x Ganter DIN6332-M12-100-SK (AF6); feet: 2x DIN6311-25-S with snap ring.

Foot flat D25 face points UP to aluminium spreader. Supplier swivel bore/pin seat is envelope only; sample fit required.

Main flange/post bolts: 4x ISO4762 M8x16 top; 4x M8x20 bottom; thread engagements12.5/13.5 mm; nominal tip gap3 mm.

Shelf mounts: 4x M6x20 + washers; tray:4x M4x10 in D8.4x3 counterbores, no washer; stops:4x M4x20. Standard-hardware static audit passes; physical seats/tools still require samples.

No printed cosmetic part transmits motor load or clamp preload. Never replace steel threaded jaw with printed polymer.

Desk thickness budget15..60; controller box budget180x150x50,3kg; box removes toward desk interior (+Y).

Base flange follows interface-contract.json independently of any arm; T01 test plate8mm + washer1.6mm gives10.4mm engagement with M6x20.

Native IO PCB Gerber/IPC356 exists separately; passive board is not an EtherCAT master/ESC or GMSL decoder.

Remaining gates: full bolts/tools/weld clearance; material/load screening; LED PCB/power; cable bend/strain relief; slicing.

After coordinated files pass: unpowered prototype build and inspection, then restrained desk/thermal/electrical tests.

This document supports design review and fabricator DFM discussion. Do not order a complete base using this file alone.

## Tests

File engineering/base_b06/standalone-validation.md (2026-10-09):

<!-- SPDX-License-Identifier: CC-BY-NC-4.0 -->
# B06 独立底座验证与生产放行

底座默认建模不再载入机械臂。承力架、桌夹、内收盒架、接口板、同轴通路、前灯和外罩分别拥有独立边界。`interface-contract.json`是接口定义，`validation-plan.json`是可机器读取的验证计划；每个试验都不要求机械臂。当前状态是**工程候选／生产验证准备**，没有实物试验，不是生产放行。

## 不装机械臂的装配

沿用[装配文件](assembly.md)的金属件、灯板、接口板、外罩和桌夹顺序，跳过机械臂裸根座、电机、顶部环及腰罩。先完成法兰上下M8螺钉，再装主罩；颈口开放，可直接从上方插入OD134的T01测试适配盘。它不改变产品外罩，也不计入五件产品打印件。八颗M6×20和ISO7089垫圈连接PCD120法兰，咬合10.4mm。后装T02测试杆，四颗M8×25和垫圈连接适配盘，咬合15.4mm。测试工装全部金属，禁止用打印件替代。

`build/standalone-test/`提供两件自制工装、24个采购螺钉/垫圈包络的分件STEP/STL、工装总装STEP、原生CAD投影和孔位表。工装与现有金属架做精确BREP检查，与当前外罩/电子件做闭合实体检查。工装本身还需要制造检验、额定销轴/叉头/吊环、加载设备校验与约束，不能直接据此开展未经约束的加载。

## 机械台架

- 桌夹：先在刚性测试台标定两根M12螺杆扭矩—夹紧力，再测试15/30/60mm实际平整桌板。旧计算中的3.6Nm不是用户安装扭矩。
- 弯矩：杆上横孔中心Z558，相对法兰Z58为500mm，水平300N对应基座150Nm；夹具自重及偏心须归零。加载分别沿正负X/Y方向。各级加载观察位移、滑移和焊缝；出现异常立即卸载。适配盘厚度、螺栓预紧和孔口应力不能由杆身名义应力计算替代。
- 轴向／水平／扭转：用独立测力源施加500N向下、100N水平及正负40Nm扭转。扭转从杆顶AF24输入；轴向加载使用经过检查的额定附件。各工况分开验证，组合载荷能力留在后续系统验证。
- 盒架：只使用180×150×50mm、3kg配重盒。检查24h变形、绑带保持和朝桌内抽取，不需要实际计算机盒。
- 实际桌面类型、预紧值、允许位移、适用寿命和使用环境最终由试验收敛。当前150Nm等是筛查/试验候选边界，未成为铭牌额定值。

## 电气台架

接口板的数据通路是无源转接；就地5V与STM32前灯控制可单独上电调试，不依赖电机驱动、机械臂控制程序或摄像机标定。

| 模块 | 独立输入与负载 | 需要保留的证据 |
|---|---|---|
| 48V通路 | 外置可限流电源、协调保护、电子负载接J4/J5 | 极性、四线电阻、连续/峰值波形、温升、故障保护；工作电流仍待明确 |
| RJ45通路 | EtherCAT主站＋独立商用从站，基座J1→J2 | 1ms过程数据、工作计数器、CRC和断链日志、直连基线；普通以太网ping不能替代 |
| 双同轴 | 校准VNA/TDR；另用两路独立序列化器/测试图源＋接收器 | CAM-A/B通道损耗、厂商掩模、PoC参数、GMSL实际错误计数 |
| 前灯 | 先用稳压5V＋独立PWM发生器验证灯板，再用接口板就地5V/STM32和内部GH线验证组合 | 亮度/电流、调光、呼吸/闪烁、复位时关灯、封闭外罩温升 |
| CHASSIS | 四线低阻仪测J6至要求连接的金属件 | 装配工艺、接触电阻、涂层处理；不能据此宣称保护接地等级 |

灯板J1：1=5V、2=PWM、3=GND；测试支路限流100mA，拟用1kHz、3.3/5V逻辑，绝不能接48V。灯板独立台架线只用于测试；产品使用接口板就地5V/PWM/GND内部短线，不另走桌下5V供电。J8 UART负责灯效命令，不能接EtherCAT口；J9为SWD检修接口。双同轴不经过接口板FR4。RJ45不包含主站、ESC、PHY或磁性器件。原生PCB检查/Gerber一致性不证明通道信号质量或电流能力。

## 验证记录与放行

21项试验覆盖制造尺寸、完整装配、插拔检修、夹紧与承载、盒架、接线、接地、48V、前灯、EtherCAT、双同轴及组合/耐久/重复制造。数值门槛是本项目提出的工程验收候选，尚需结合实际工艺和工况批准。

`qualification.py init --record 路径`生成空记录，不能覆盖已有记录。填写序列号、测试日期、操作/复核人、校准有效的仪器、实际测量值和证据文件SHA256，再执行`qualification.py evaluate --record 路径`。缺失值、过期校准、证据文件变化、版本变化或未关闭的定义项都会阻止通过。记录校验无法保证证据真实性；即使全部通过也必须由负责人员执行正式放行，脚本不会自动放行生产。

需要关闭七项定义缺口：焊接工艺、实际连接器/线材配合、完整线束、工作电流与PoC/GMSL要求、打印/光学工艺、加载装置自身资格、最终图纸/BOM与首件审批。当前测试模板所有实测值为空，状态如实为BLOCKED。`refresh-unmeasured`只允许刷新完全未填写的模板；已有序列号、配置或任何测量/证据的记录一律拒绝覆盖。

## 版本与复现

默认入口`blender_standalone_entry.py`对Python文件访问加审计，访问`root-snapshot.json`或机械臂目录立即报错。机械臂参考只能通过`blender_compact.py -- --with-arm-root --no-render`主动启用，输出到独立`build/arm-integration/`，不会覆盖当前底座。

用含CadQuery的Python运行`verify_base.py --blender /绝对路径/Blender`可重建金属架、工装、外罩，运行数字检查、原生制造数据审计、打包与查看器。实际切片评审会复核既有3MF，若改变打印网格，必须先重新切片；它不会把旧切片当成新的结果。物理台架试验另外执行和记录。

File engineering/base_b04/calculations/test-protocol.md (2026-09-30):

# B04 无动力台架验证协议候选

SPDX-License-Identifier: CC-BY-NC-4.0
Attribution: Odradek — Auromix contributors (https://github.com/Auromix/odradek)

本协议是待执行的试验计划，没有任何已完成实测结果。先在固定于试验台的刚性金属桌边检具上验证金属夹具，再验证具体型号/材料的桌板。15/30/60 mm 是三个厚度检具，不能由这三次几何试装推出所有木桌都适配。使用独立加载假法兰和受控加载装置，不装整臂、不开电机、不以真实负载抓取代替夹具台架试验。

## 试件和记录

- 记录零件版本、STEP/图纸 SHA、各板材材质证明、实测厚度、孔距、平面度、完整牙长及螺钉/垫圈批次；特别测 deck 沉孔余壁 3.5 mm、C 后脊 M6 孔及 R5 根部。
- 两压足各布置一个压缩力传感器；传感器占用厚度必须由检具或专用测力压板补偿，保持计算中的压足力线、跨度和支承接触面，不能直接把传感器塞入既有间隙后称原结构验证。
- 记录驱动扭矩、左右保留夹紧力、桌夹与检具相对位移、加载法兰位移/转角、C 后脊开口及局部应变。用压敏膜或等效可定量接触测量检查接触区，不能假设整块软垫均匀受压。
- 桌厚 15/30/60 mm 分别检查 AF6 工具全行程、压足/卡环活动、螺杆顶端和全牙区、盒架与工具空间；收货实物浮动足的摆角要重测。

## 夹紧力与扭矩标定

1. 保持零外部倾覆力矩，从接触开始小步增加扭矩，每步不大于 0.25 N·m；每步记录两路实际夹紧力和 C 后脊应变/开口。
2. 未完成局部结构复核前，先到每根 0.5 kN，卸载检查；再逐级 1.0/1.5/2.0 kN。计算中 2.5 kN 是待评估工作点，不能因为有这个表格就自动继续加载到该点。
3. 只有前级无异常且局部材料/几何复核认可后，才试 2.5 kN 平均值、左右相对均值差不大于 ±10%。该要求指测得保留力，不是扭矩值相同。
4. 观察 10 min、30 min 和 8 h 保留力；本轮建议以相对稳定后读数损失不超过 15% 作为探索性判据，尚未成为正式产品要求。再重复至少 10 次装卸，记录摩擦、润滑、污染和接触印迹变化。
5. 未经实测标定，不设置用户安装扭矩。停止阈值取“获准的实测夹紧力、获准应变/位移、螺纹/桌板损伤或工具扭矩阈值”中最先达到者。不能用普通 M12 螺栓的额定拧紧扭矩套用球/点端夹紧螺杆。

## 刚性检具加载

加载点为 `(0,135,58) mm`。以下 500 N、100 N·m、100 N、30 N·m 均为研究设计包络；不称实机需求已经测定。金属夹具自身重力自然存在，100 N 基座预留不能再整份作为附加砝码重复叠加；若要补足包络，仅补其与实测基座重量之差并记录位置。盒体独立按 3 kg 在中心 `(0,195,-145) mm` 配重。

1. 独立施加竖向 125/250/375/500 N；在各级观察并卸载检查。
2. 保持竖向 500 N，分别做 `Mx=±25/50/75/100 N·m`，再分别做 `My=±25/50/75/100 N·m`。两正交 100 N·m 不在本合同中同时施加。
3. 完成单项后，按加载装置能力加入同一工况的水平力 25/50/75/100 N 和 `Mz=±30 N·m`，至少覆盖 ±X、±Y 及使夹紧力差增大的方向。假法兰/杠杆/测力计自身必须有独立的尺寸、刚度和量程校核；例如使用对置测力形成纯力偶时，两力合量应接近零，不把额外净力漏记。
4. 每级保持 60 s，最高研究工况保持 10 min；记录全程夹紧力，不能只看加载前预紧。加载一旦导致明显滑移、失去压紧、永久变形、裂纹、螺纹拉伤或异常压痕，立即卸载并判该阶段不通过，不追加拧紧掩盖问题。
5. 探索性尺寸门槛可先记录为相对滑移 ≤0.2 mm、卸载残余位移 ≤0.1 mm；法兰弹性转角 ≤0.25°作为待确认刚度目标。它们是本轮测试建议，尚非用户验收标准，也不代表疲劳寿命。

还必须重复较低竖向载荷/移除盒子的组合，尤其纯力偶情况下不施加500N假法兰竖载的工况。实际夹具自重保留并测量，不能制造“零质量夹具”。500N不是所有工况可依赖的稳定重量；计算显示2.5kN平均夹力、±10%不均、假设μ=.2不足以证明所有低重量滚转场景，因此不得跳过这一阶段或先声称全包络通过。

## 桌板与托盘

- 具体桌板通过目视结构核查后，在相同厚度/材料/表层/支承跨度的样件上重复从低级开始的夹紧与加载。测局部压痕、分层、面板弯曲、桌腿/横梁位移和 8 h 蠕变；不能只验证表面不滑。蜂窝、空心、玻璃等材料不由本计划默认纳入。
- 软垫摩擦试验应使用真实板面、干湿/灰尘条件及实际压力区间；记录首次滑移载荷。报告所用 μ=0.1/0.2/0.3/0.4 都是敏感性参数，不能预先写为硅胶材料指标。
- 外置盒先用 3 kg 检具验证托盘、止挡、绑带和向桌内抽取；卸盒不应松主夹紧螺杆。3 kg静载不等于维护时手拉/撞击负载已验证，后者需另定工况。
- 塑料压足卡环只做离桌搬运和装拆防掉落试验。确认金属钢足在所有规定姿态都直接接触铝压板，夹紧载荷不得经打印唇边传递。

最终记录须区分：几何试装、金属检具静载、特定桌板试验、动态/疲劳。任何阶段通过都不能越级替代下一阶段。

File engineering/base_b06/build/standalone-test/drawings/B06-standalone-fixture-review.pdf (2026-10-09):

## AUROMIX / ODRADEK | B06-TEST-01 | B06-T01-TEST-ADAPTER

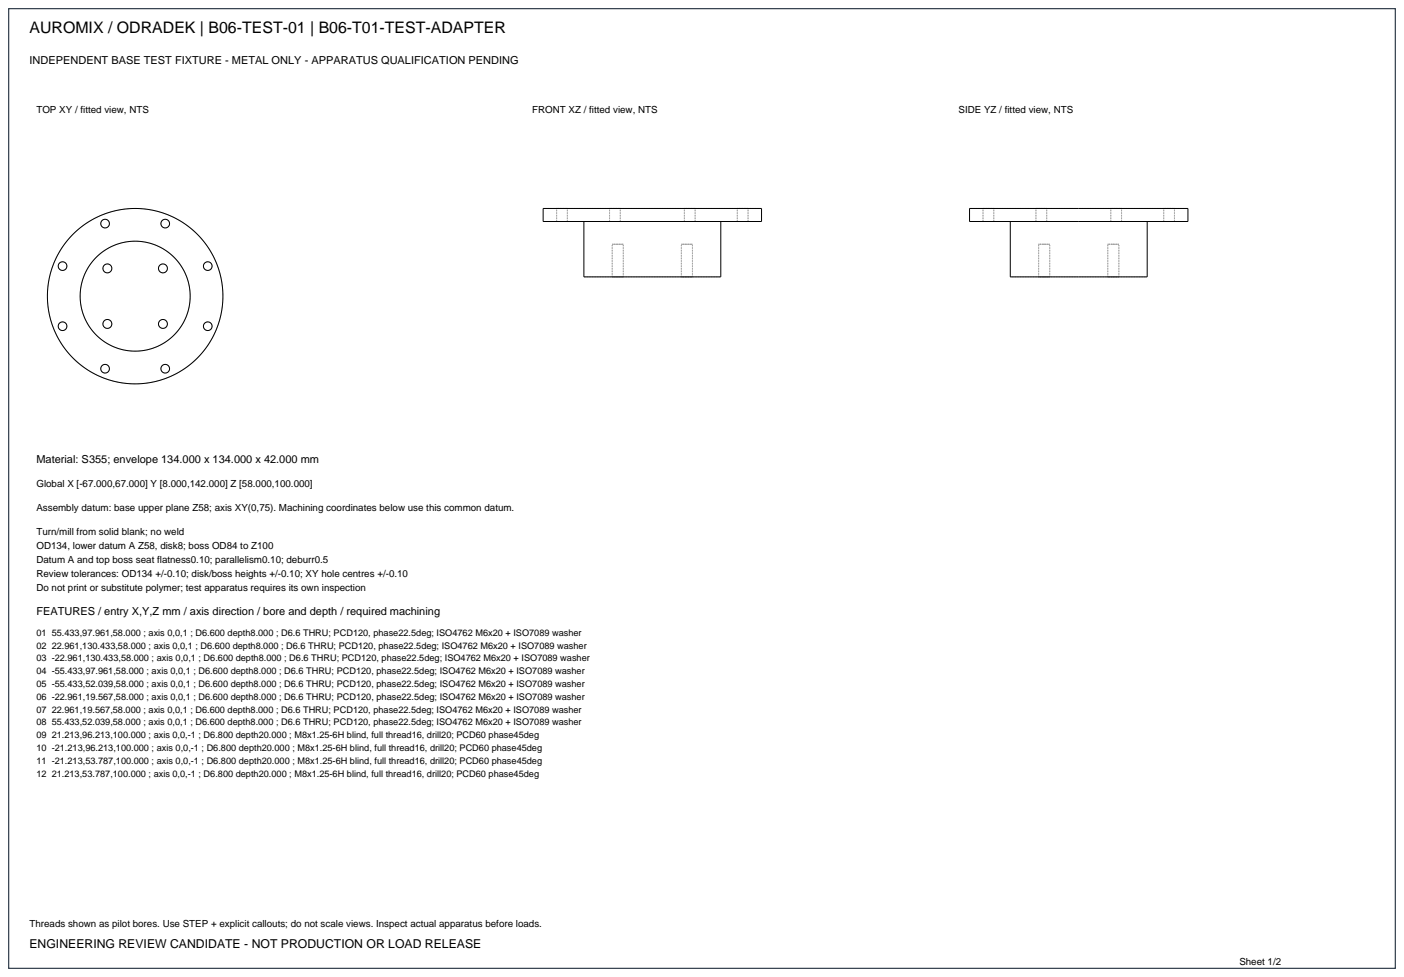
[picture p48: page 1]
TOP XY / fitted view, NTS; FRONT XZ / fitted view, NTS; SIDE YZ / fitted view, NTS; Global X [-67.000,67.000] Y [8.000,142.000] Z [58.000,100.000]; Sheet 1/2

INDEPENDENT BASE TEST FIXTURE - METAL ONLY - APPARATUS QUALIFICATION PENDING

Material: S355; envelope 134.000 x 134.000 x 42.000 mm

Assembly datum: base upper plane Z58; axis XY(0,75). Machining coordinates below use this common datum.

Turn/mill from solid blank; no weld
OD134, lower datum A Z58, disk8; boss OD84 to Z100
Datum A and top boss seat flatness0.10; parallelism0.10; deburr0.5
Review tolerances: OD134 +/-0.10; disk/boss heights +/-0.10; XY hole centres +/-0.10
Do not print or substitute polymer; test apparatus requires its own inspection
FEATURES / entry X,Y,Z mm / axis direction / bore and depth / required machining

01 55.433,97.961,58.000 ; axis 0,0,1 ; D6.600 depth8.000 ; D6.6 THRU; PCD120, phase22.5deg; ISO4762 M6x20 + ISO7089 washer
02 22.961,130.433,58.000 ; axis 0,0,1 ; D6.600 depth8.000 ; D6.6 THRU; PCD120, phase22.5deg; ISO4762 M6x20 + ISO7089 washer
03 -22.961,130.433,58.000 ; axis 0,0,1 ; D6.600 depth8.000 ; D6.6 THRU; PCD120, phase22.5deg; ISO4762 M6x20 + ISO7089 washer
04 -55.433,97.961,58.000 ; axis 0,0,1 ; D6.600 depth8.000 ; D6.6 THRU; PCD120, phase22.5deg; ISO4762 M6x20 + ISO7089 washer
05 -55.433,52.039,58.000 ; axis 0,0,1 ; D6.600 depth8.000 ; D6.6 THRU; PCD120, phase22.5deg; ISO4762 M6x20 + ISO7089 washer
06 -22.961,19.567,58.000 ; axis 0,0,1 ; D6.600 depth8.000 ; D6.6 THRU; PCD120, phase22.5deg; ISO4762 M6x20 + ISO7089 washer
07 22.961,19.567,58.000 ; axis 0,0,1 ; D6.600 depth8.000 ; D6.6 THRU; PCD120, phase22.5deg; ISO4762 M6x20 + ISO7089 washer
08 55.433,52.039,58.000 ; axis 0,0,1 ; D6.600 depth8.000 ; D6.6 THRU; PCD120, phase22.5deg; ISO4762 M6x20 + ISO7089 washer
09 21.213,96.213,100.000 ; axis 0,0,-1 ; D6.800 depth20.000 ; M8x1.25-6H blind, full thread16, drill20; PCD60 phase45deg
10 -21.213,96.213,100.000 ; axis 0,0,-1 ; D6.800 depth20.000 ; M8x1.25-6H blind, full thread16, drill20; PCD60 phase45deg
11 -21.213,53.787,100.000 ; axis 0,0,-1 ; D6.800 depth20.000 ; M8x1.25-6H blind, full thread16, drill20; PCD60 phase45deg
12 21.213,53.787,100.000 ; axis 0,0,-1 ; D6.800 depth20.000 ; M8x1.25-6H blind, full thread16, drill20; PCD60 phase45deg

Threads shown as pilot bores. Use STEP + explicit callouts; do not scale views. Inspect actual apparatus before loads.
ENGINEERING REVIEW CANDIDATE - NOT PRODUCTION OR LOAD RELEASE

## AUROMIX / ODRADEK | B06-TEST-01 | B06-T02-TEST-POST

INDEPENDENT BASE TEST FIXTURE - METAL ONLY - APPARATUS QUALIFICATION PENDING

TOP XY / fitted view, NTS | FRONT XZ / fitted view, NTS | SIDE YZ / fitted view, NTS

Material: S355; envelope 84.000 x 84.000 x 508.000 mm

Global X [-42.000,42.000] Y [33.000,117.000] Z [100.000,608.000]

Assembly datum: base upper plane Z58; axis XY(0,75). Machining coordinates below use this common datum.

Turn/mill from solid blank; no weld
Flange OD84 x8, shaft OD30 from Z108 to588, top AF24 x20; top Z608
Datum A flange underside Z100; flatness0.10; shaft perpendicularity0.15 over500
Review tolerances: OD30 +/-0.10; flange thickness +/-0.10; hole centres +/-0.10
Lateral force applied at Z558, 500mm above base datum; 300N gives150Nm at base
Top AF24 is torque-test drive; axial load through inspected rated M10 lifting accessory, not printed hardware

FEATURES / entry X,Y,Z mm / axis direction / bore and depth / required machining

01 21.213,96.213,100.000 ; axis 0,0,1 ; D8.500 depth8.000 ; D8.5 THRU; ISO4762 M8x25 + ISO7089 washer
02 -21.213,96.213,100.000 ; axis 0,0,1 ; D8.500 depth8.000 ; D8.5 THRU; ISO4762 M8x25 + ISO7089 washer
03 -21.213,53.787,100.000 ; axis 0,0,1 ; D8.500 depth8.000 ; D8.5 THRU; ISO4762 M8x25 + ISO7089 washer
04 21.213,53.787,100.000 ; axis 0,0,1 ; D8.500 depth8.000 ; D8.5 THRU; ISO4762 M8x25 + ISO7089 washer
05 -16.000,75.000,558.000 ; axis 1,0,0 ; D8.500 depth32.000 ; D8.5 THRU, load-pin centre Z558; rated pin/clevis selection pending 06 0.000,75.000,608.000 ; axis 0,0,-1 ; D8.500 depth20.000 ; M10x1.5-6H blind; full thread15, drill20; rated axial lifting accessory

Threads shown as pilot bores. Use STEP + explicit callouts; do not scale views. Inspect actual apparatus before loads.

### ENGINEERING REVIEW CANDIDATE - NOT PRODUCTION OR LOAD RELEASE

Sheet 2/2

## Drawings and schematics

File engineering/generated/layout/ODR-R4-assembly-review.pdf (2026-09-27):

# ODRADEK / 工程装配布局

## 零位 / 四片展开 / 实际模型正交投影 / 未完成实体可达及承载验证

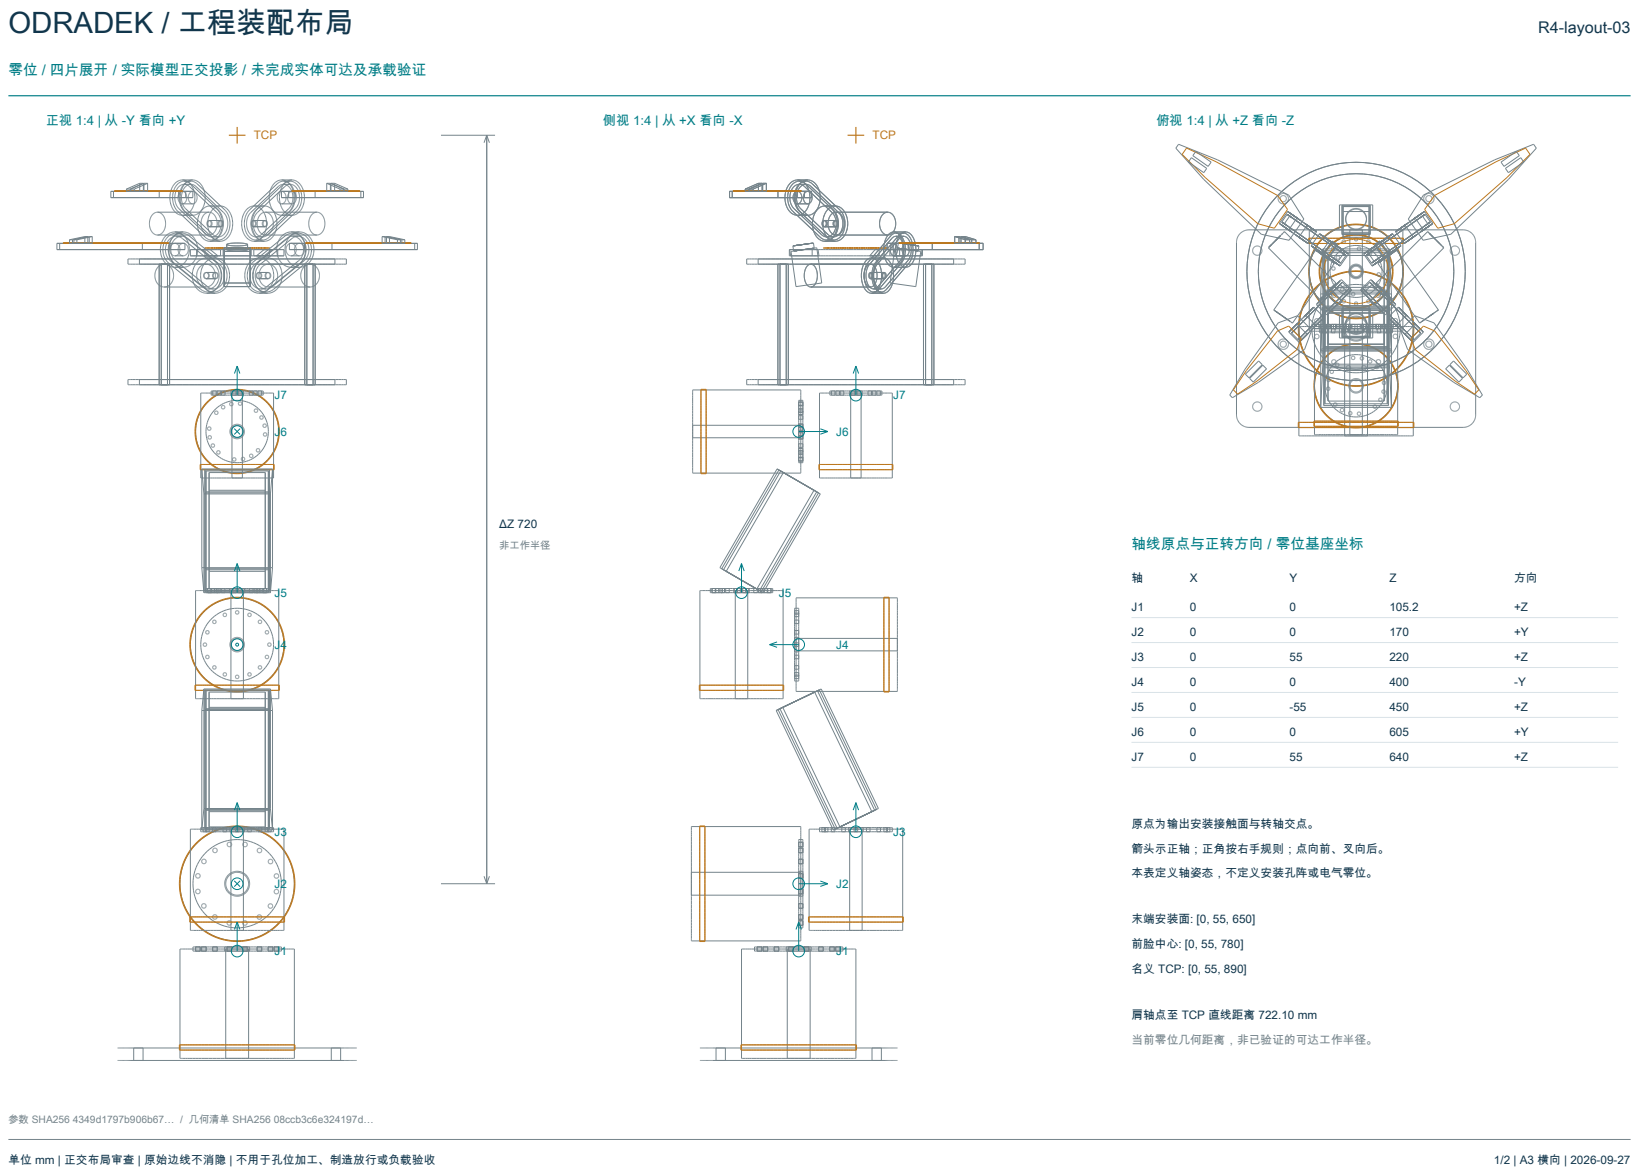
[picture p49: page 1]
R4-layout-03; TCP; 非工作半径; 轴线原点与正转方向 / 零位基座坐标; 原点为输出安装接触面与转轴交点。; 本表定义轴姿态，不定义安装孔阵或电气零位。; 末端安装面: [0, 55, 650]; 前脸中心: [0, 55, 780]; 名义 TCP: [0, 55, 890]; 当前零位几何距离，非已验证的可达工作半径。; 单位 mm | 正交布局审查 | 原始边线不消隐 | 不用于孔位加工、制造放行或负载验收; 参数 SHA256 4349d1797b906b67… / 几何清单 SHA256 08ccb3c6e324197d…

箭头示正轴；正角按右手规则；点向前、叉向后。

肩轴点至 TCP 直线距离 722.10 mm

# ODRADEK / 末端与接口布局

## 四独立灯片 / 上长下短 / 下根向前错层 / 仅审查装配空间

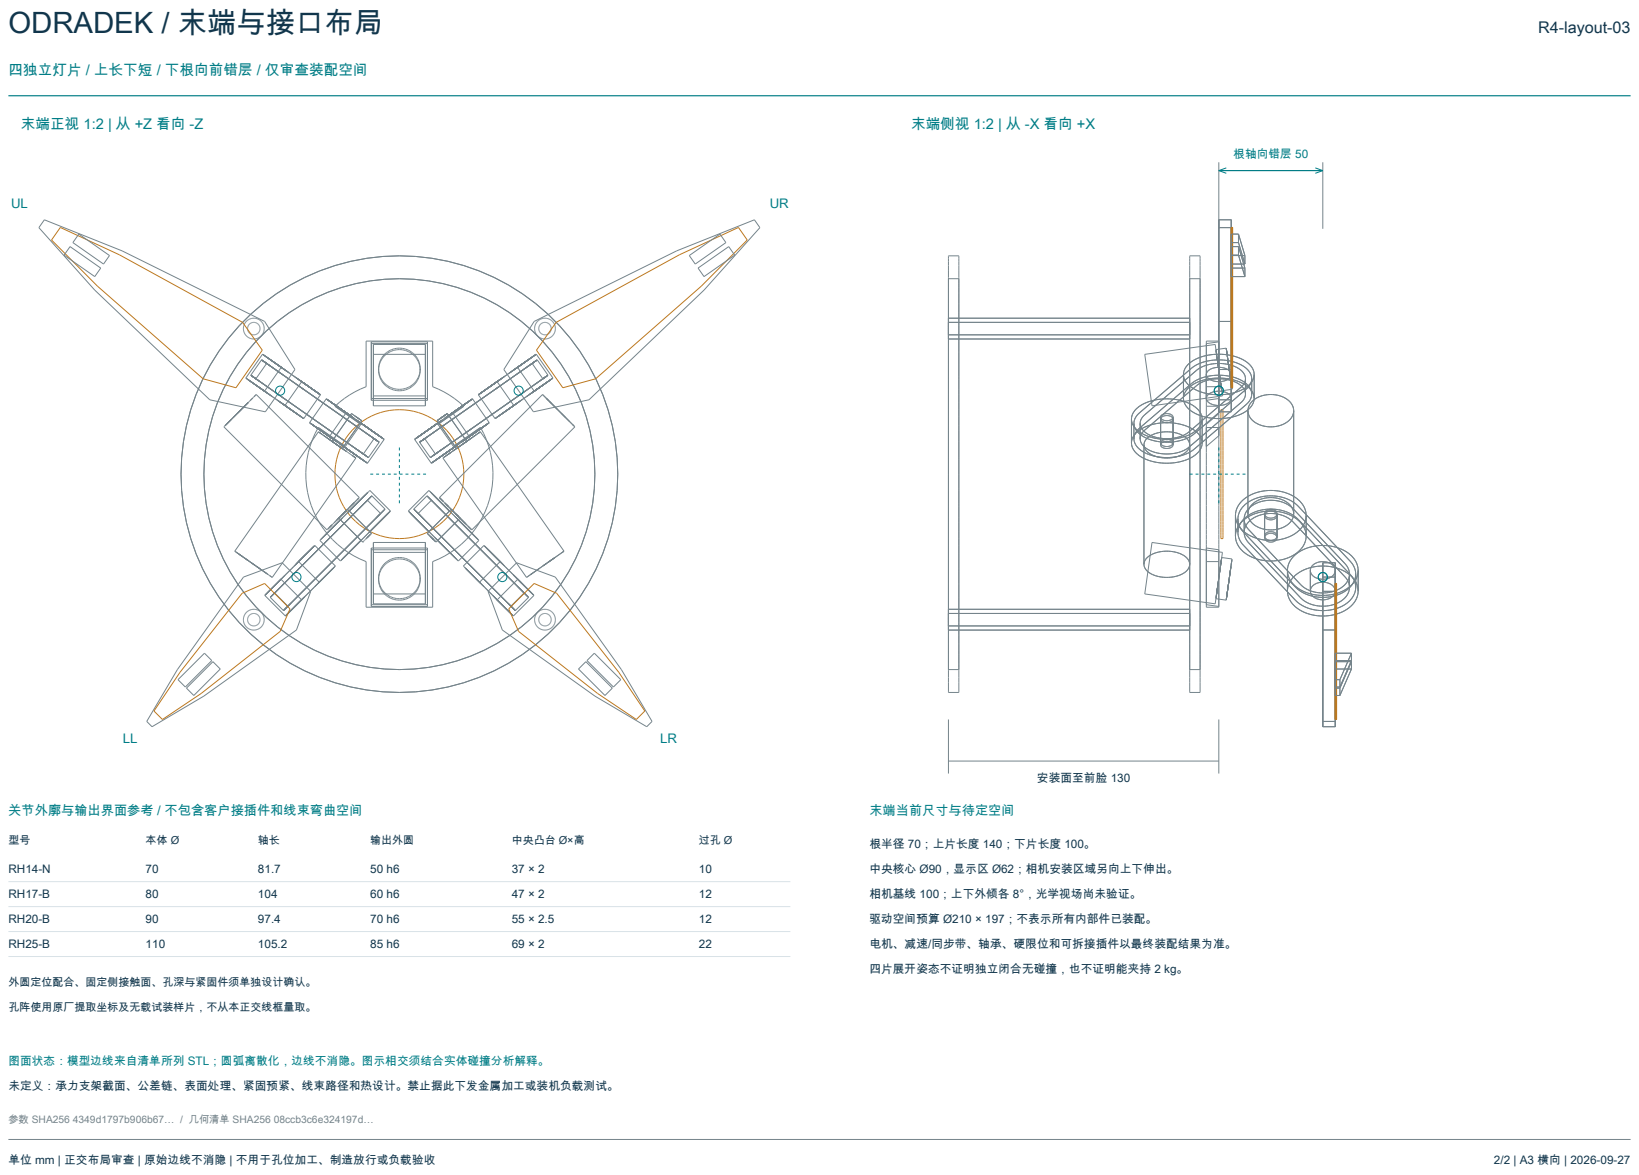
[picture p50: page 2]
R4-layout-03; 末端正视 1:2 | 从 +Z 看向 -Z; 末端侧视 1:2 | 从 -X 看向 +X; 根轴向错层 50; 安装面至前脸 130; 关节外廓与输出界面参考 / 不包含客户接插件和线束弯曲空间; 输出外圆; 中央凸台 Ø×高; 孔阵使用原厂提取坐标及无载试装样片，不从本正交线框量取。; 末端当前尺寸与待定空间; 驱动空间预算 Ø210 × 197；不表示所有内部件已装配。; 单位 mm | 正交布局审查 | 原始边线不消隐 | 不用于孔位加工、制造放行或负载验收; 参数 SHA256 4349d1797b906b67… / 几何清单 SHA256 08ccb3c6e324197d…

根半径 70；上片长度 140；下片长度 100。

中央核心 Ø90，显示区 Ø62；相机安装区域另向上下伸出。

相机基线 100；上下外倾各 8°，光学视场尚未验证。

电机、减速/同步带、轴承、硬限位和可拆接插件以最终装配结果为准。

四片展开姿态不证明独立闭合无碰撞，也不证明能夹持 2 kg。

外圆定位配合、固定侧接触面、孔深与紧固件须单独设计确认。

图面状态：模型边线来自清单所列 STL；圆弧离散化，边线不消隐。图示相交须结合实体碰撞分析解释。

未定义：承力支架截面、公差链、表面处理、紧固预紧、线束路径和热设计。禁止据此下发金属加工或装机负载测试。

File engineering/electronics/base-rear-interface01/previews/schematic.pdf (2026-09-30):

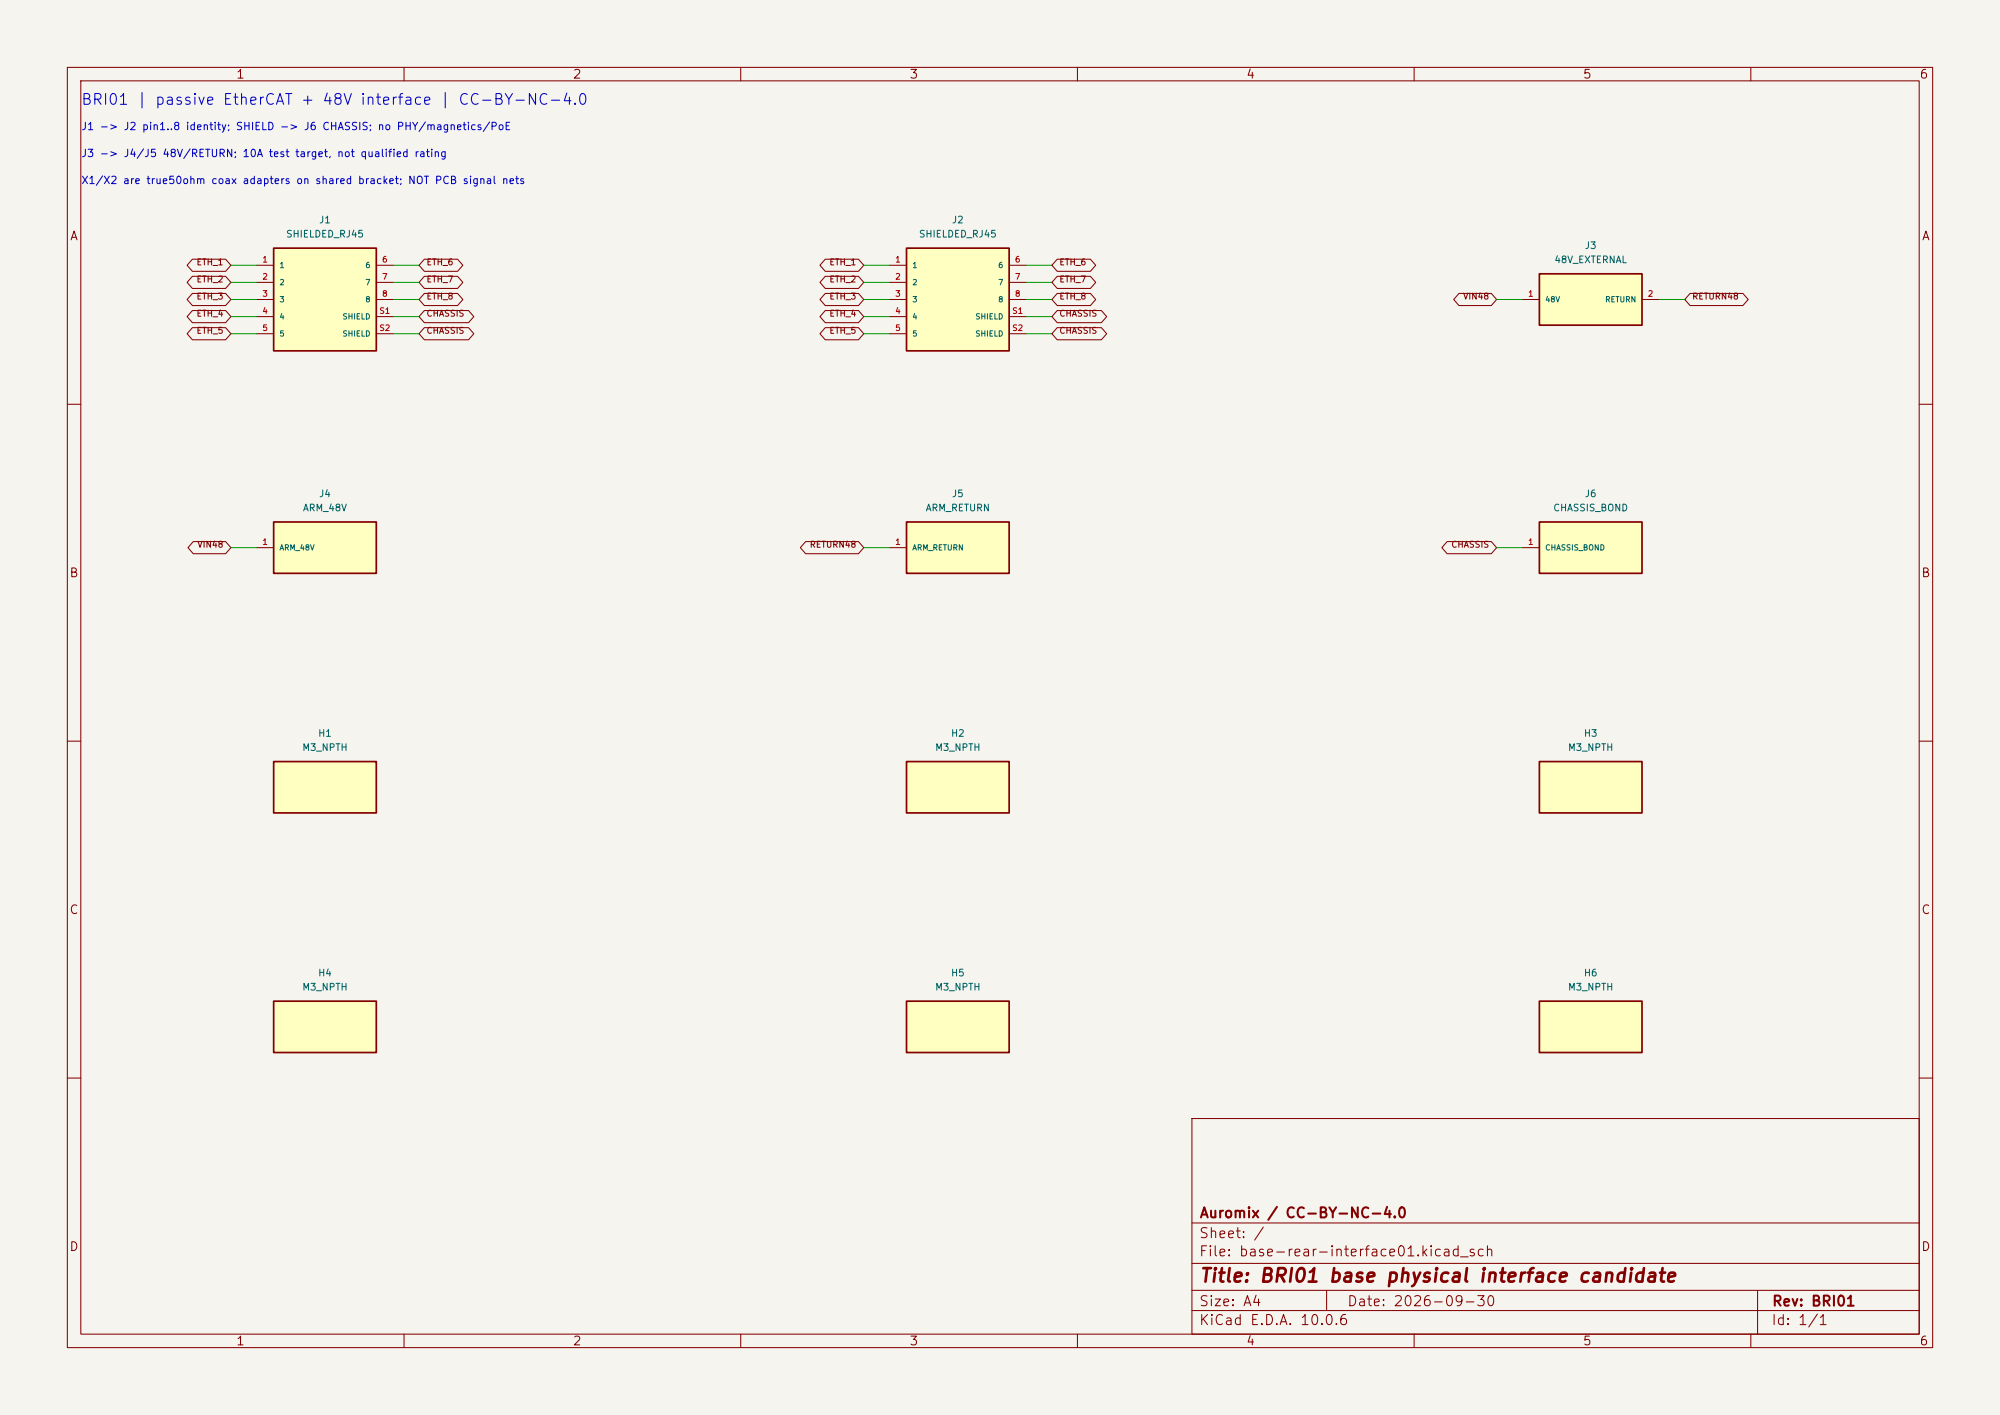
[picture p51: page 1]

BRI01 | passive EtherCAT + 48V interface | CC-BY-NC-4.0

J1 -> J2 pin1..8 identity; SHIELD -> J6 CHASSIS; no PHY/magnetics/PoE

J3 -> J4/J5 48V/RETURN; 10A test target, not qualified rating

ETH_4 X1/X2 are true50ohm coax adapters on shared bracket; NOT PCB signal nets

Auromix / CC-BY-NC-4.0
Sheet: /
File: base-rear-interface01.kicad_sch
Title: BRI01 base physical interface candidate

Size: A4 | Rev: BRI01
KiCad E.D.A. 10.0.6 | Id: 1/1

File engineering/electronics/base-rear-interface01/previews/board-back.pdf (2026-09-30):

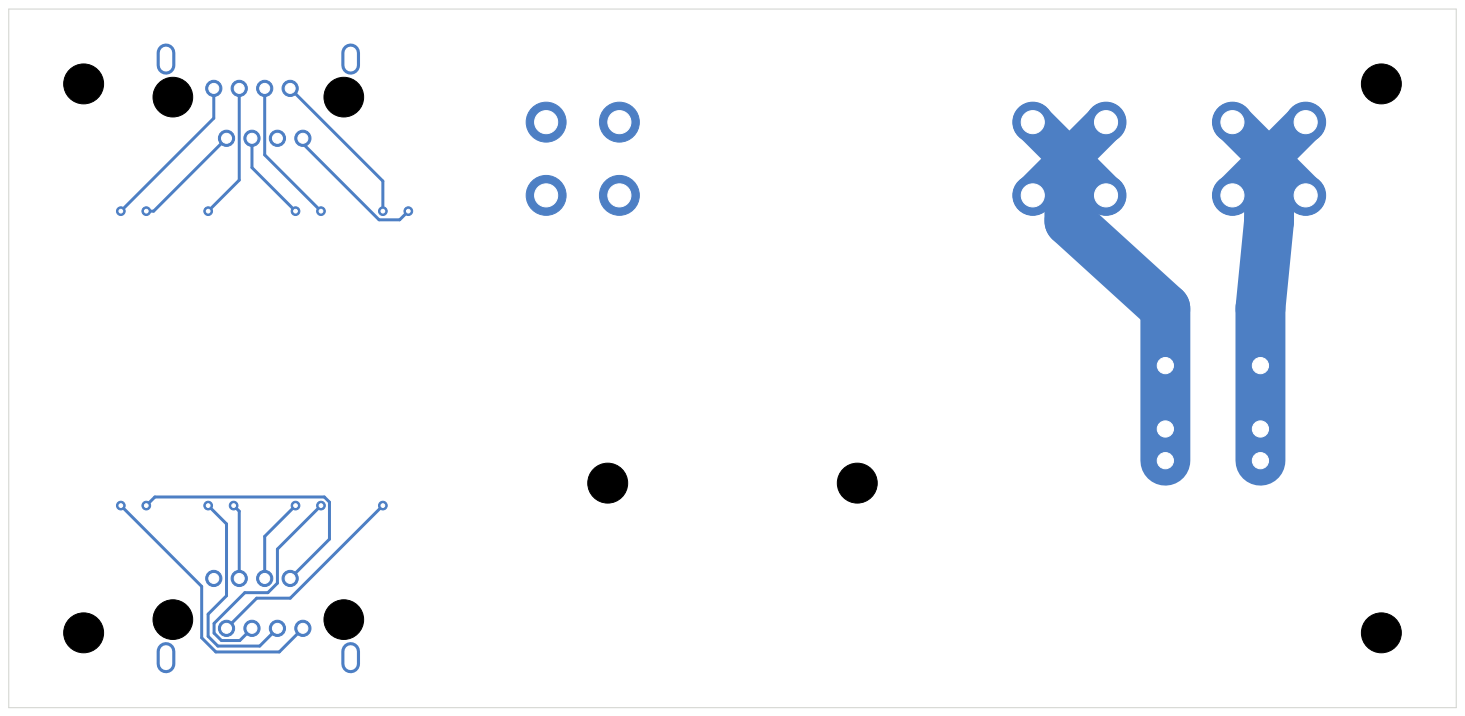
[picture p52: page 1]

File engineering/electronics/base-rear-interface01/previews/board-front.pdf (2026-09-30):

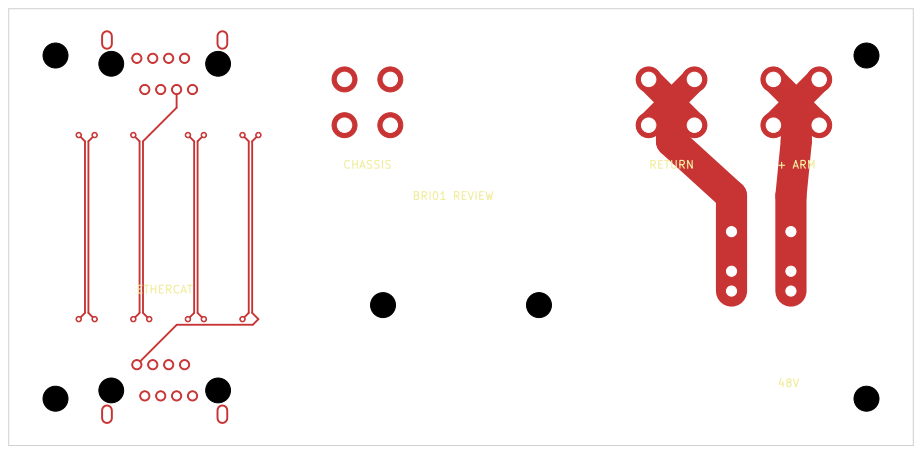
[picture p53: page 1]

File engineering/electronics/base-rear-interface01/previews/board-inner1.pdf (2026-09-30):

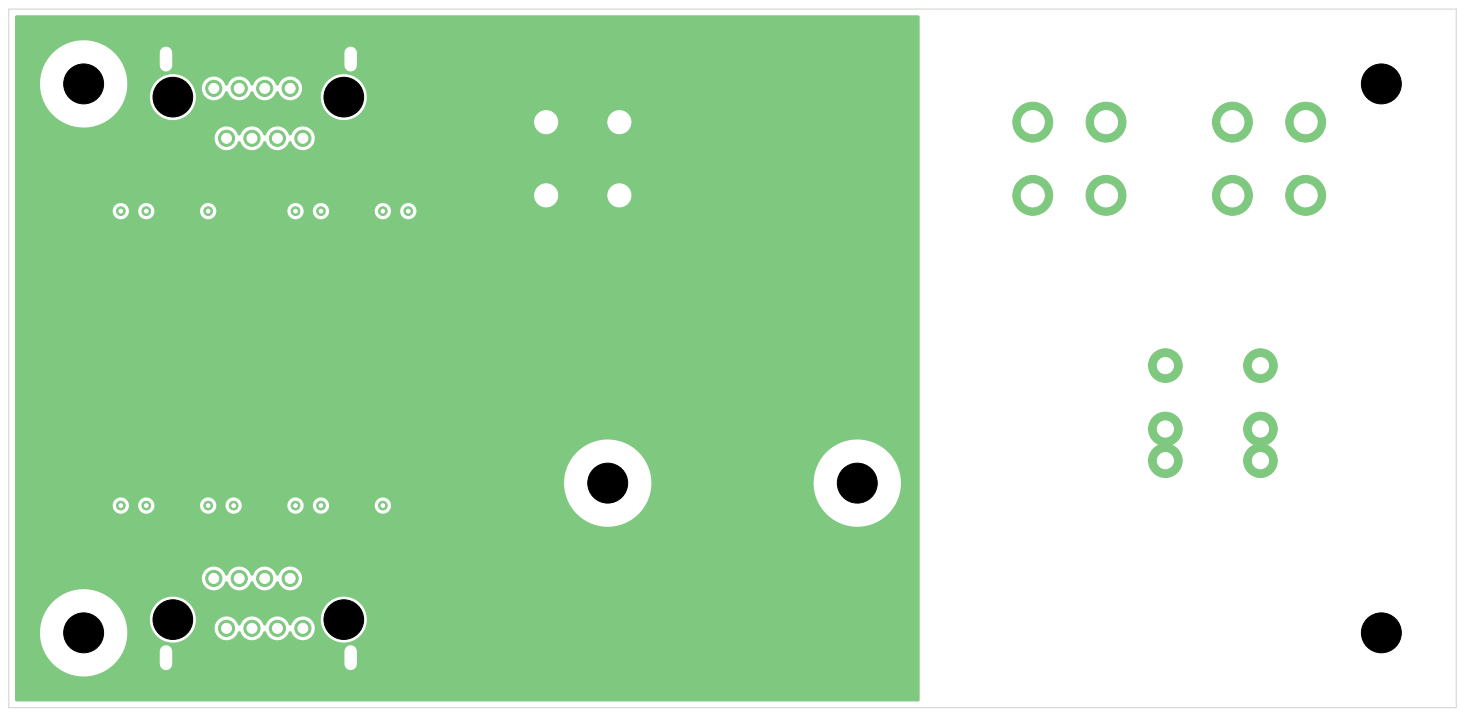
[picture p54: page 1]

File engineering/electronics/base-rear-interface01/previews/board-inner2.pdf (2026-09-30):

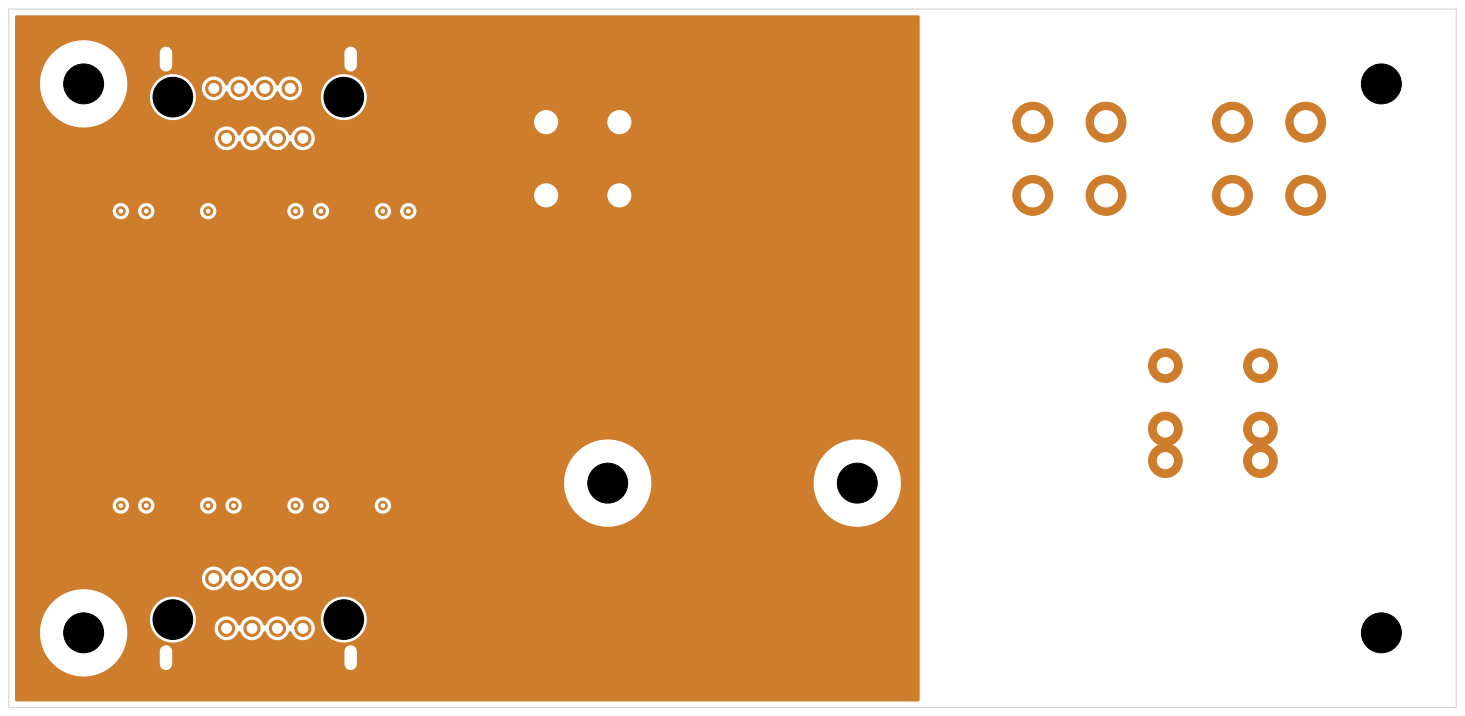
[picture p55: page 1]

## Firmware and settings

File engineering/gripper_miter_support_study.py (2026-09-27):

#!/usr/bin/env python3
# SPDX-License-Identifier: CC-BY-NC-4.0
# Required Notice: Odradek — Auromix contributors (https://github.com/Auromix/odradek)
"""R4-support-02: axial motors / 90-degree miter spindle feasibility study.
Nominal external envelopes, not tooth-generated CAD or released manufacturing.
Requires numpy and matplotlib; --cad adds cadquery. Shared layout is read-only.
"""
from pathlib import Path
import argparse, hashlib, itertools, json, math
import numpy as np
ROOT=Path(__file__).resolve().parents[1]
OUT=ROOT/'engineering/generated/gripper-support-02'
EXPECTED='4349d1797b906b67a7bc396fcb84bc439c2d70dd0b337659e552cee293d2dd81'
P=dict(revision='R4-support-02',gear='MMSB1.5-20R + MMSB1.5-20L',module_mm=1.5,teeth=20,
       gear_OD_mm=31.9,gear_bore_mm=12,gear_hub_D_mm=25,gear_E_mm=28,gear_F_mm=18.48,
       gear_G_mm=13.95,gear_H_mm=10.5,gear_I_mm=16.5,gear_b_mm=7,
       alpha_deg=20,beta_deg=35,delta_deg=45,bending_catalog_Nm=7.74,surface_catalog_Nm=7.34,
       torque_screen_Nm=3.7,bearing='SKF 7201 BECBP, adjacent DB pair per shaft',
       bearing_d_mm=12,bearing_D_mm=32,bearing_B_mm=10,bearing_C_N=7610,bearing_C0_N=3800,
       housing_D_mm=40,housing_front_mm=28.5,housing_back_mm=52,
       shaft_shoulder_D_mm=17.3,shaft_E_MPa_assumption=205000,
       coupling='NBK MJC-20CS-EGR-6-10',coupling_D_mm=20,coupling_L_mm=30,coupling_insert_mm=10,
       motor_D_mm=22,motor_body_L_mm=70.1,motor_shaft_L_mm=16.3,
       side_plate_radial_outer_mm=22,nominal_head_reference_D_mm=210,nominal_head_reference_depth_mm=197,
       gap_screen_mm=1)
Z=np.array([0.,0.,1.])
def v(x):return np.asarray(x,dtype=float)
def stack():
    # t is positive from the gear-axis intersection toward each shaft's rear.
    # DB pair is directly adjacent, retaining the catalog's CB matching condition.
    return dict(gear=[9.52,28],gear_tooth_envelope=[9.52,17.5],gear_hub=[17.5,28],
        gear_bore_end=11.5,gear_retention_washer=[10,11.5],gear_retention_bolt=[7.2,10],
        shoulder=[28,30],bearing_A=[30,40],bearing_B=[40,50],bearing_centers=[35,45],
        bearing_pressure_center_span_mm=28, # DB: 2*a, SKF a=14. Not used as a strength approval.
        rear_spacer=[50,52],MB1=[52,53],KM1=[53,57],thread_bay=[52,58],
        input_shaft=[11.5,69],coupling=[59,89],input_coupling_end=[59,69],
        motor_shaft=[79,95.3],motor_body=[95.3,165.4],motor_flange=[93.3,95.3],
        output_shaft=[11.5,69],finger_hub=[59,69],finger_hub_center=64,
        apex_offset_along_finger_axis_mm=64)

def box(name,group,c,axes,half,kind,**kw):
    return dict(name=name,group=group,center=v(c),axes=np.column_stack(axes),half=v(half),kind=kind,**kw)
def corners(p):
    return p['center']+(np.array(list(itertools.product([-1.,1.],repeat=3)))*p['half'])@p['axes'].T

def sat(a,b):
    A=a['axes'];B=b['axes'];D=b['center']-a['center']
    axes=np.concatenate([A.T,B.T,np.cross(A.T[:,None,:],B.T[None,:,:]).reshape(-1,3)])
    axes=axes[np.linalg.norm(axes,axis=1)>1e-9];axes/=np.linalg.norm(axes,axis=1)[:,None]
    return float(max(np.abs(axes@D)-np.abs(axes@A)@a['half']-np.abs(axes@B)@b['half']))

def make_parts(layout,signs):
    parts=[];rows=[];s=stack()
    for i,f in enumerate(layout['head']['fingers']):
        phi=math.radians(f['phi_deg']);er=v([math.cos(phi),math.sin(phi),0]);et=v([-math.sin(phi),math.cos(phi),0]);u=signs[i]*et
        anchor=f['root_radius_mm']*er+f['root_z_mm']*Z;apex=anchor+s['finger_hub_center']*u;name=f['id']
        def cyl(label,origin,axis,lim,r,kind,bore=0,**kw):
            w=np.cross(axis,er)
            parts.append(box(name+'_'+label,i,origin+axis*(sum(lim)/2),[axis,er,w],[(lim[1]-lim[0])/2,r,r],kind,shape='cylinder',bore_mm=bore,**kw))
        def block(label,uc,zc,rc,usize,zsize,rsize,kind):
            parts.append(box(name+'_'+label,i,apex+uc*u+zc*Z+rc*er,[u,Z,er],[usize/2,zsize/2,rsize/2],kind,shape='box'))
        for role,axis in [('input',-Z),('output',-u)]:
            cyl(role+'_gear_tooth_envelope',apex,axis,s['gear_tooth_envelope'],15.95,'gear_envelope',12)
            cyl(role+'_gear_hub',apex,axis,s['gear_hub'],12.5,'gear_hub',12)
            cyl(role+'_gear_front_washer',apex,axis,s['gear_retention_washer'],8,'gear_retention',4.3)
            cyl(role+'_gear_front_bolt_allowance',apex,axis,s['gear_retention_bolt'],3.8,'bolt_allowance')
            cyl(role+'_gear_seat',apex,axis,[11.5,28],6,'shaft')
            cyl(role+'_shaft_shoulder',apex,axis,s['shoulder'],8.65,'shaft_shoulder')
            cyl(role+'_bearing_journal',apex,axis,[30,52],6,'shaft')
            cyl(role+'_thread_bay',apex,axis,s['thread_bay'],6,'shaft_thread')
            cyl(role+'_rear_spacer',apex,axis,s['rear_spacer'],8.65,'spacer',12)
            cyl(role+'_MB1_allowance',apex,axis,s['MB1'],12.5,'lockwasher',12)
            cyl(role+'_KM1',apex,axis,s['KM1'],11,'locknut',12)
            for side in ['A','B']:
                cyl(role+'_bearing_'+side,apex,axis,s['bearing_'+side],16,'bearing',12)
            # Housing has a 32 mm bore and separate two outer-ring abutment lips.
            cyl(role+'_housing',apex,axis,[30,50],20,'housing',32)
            cyl(role+'_housing_front_lip',apex,axis,[28.5,30],20,'housing_lip',27.5)
            cyl(role+'_housing_rear_cap',apex,axis,[50,52],20,'housing_lip',28)
        cyl('input_coupler_tenon',apex,-Z,[58,69],5,'shaft')
        cyl('output_hub_tenon',apex,-u,[58,69],6,'shaft')
        cyl('finger_metal_hub',apex,-u,s['finger_hub'],12,'finger_hub',12)
        cyl('coupling',apex,-Z,s['coupling'],10,'coupling')
        cyl('motor_shaft',apex,-Z,s['motor_shaft'],3,'motor_shaft')
        cyl('motor',apex,-Z,s['motor_body'],11,'motor')
        cyl('motor_flange',apex,-Z,s['motor_flange'],17,'motor_mount',10.5)
        # Two metal side plates connect the cartridge housings behind the mesh.
        # Machined holes, screws, split seams, gear enclosure and seals remain detailed-design work.
        for sign in [-1,1]:
            block('side_plate_input_'+str(sign),-27.5,-40,sign*20,61,24,4,'carrier_plate')
            block('side_plate_output_'+str(sign),-40,-13,sign*20,24,30,4,'carrier_plate')
            block('motor_rail_'+str(sign),0,-72.65,sign*15,6,41.3,4,'motor_mount')
        rows.append(dict(finger=name,root_anchor_mm=anchor,axis_u=u,apex_mm=apex,
            motor_axis_point_mm=apex,motor_front_center_mm=apex-95.3*Z,
            motor_rear_center_mm=apex-165.4*Z,finger_hub_center_mm=apex-64*u,
            input_axis=[0,0,-1],output_axis=(-u),root_z_mm=f['root_z_mm']))
    return parts,rows

def collisions(parts):
    pairs=[]
    for a,b in itertools.combinations(parts,2):
        if a['group']==b['group']:continue
        d=sat(a,b)
        if d<P['gap_screen_mm']-1e-9:pairs.append(dict(a=a['name'],b=b['name'],projection_gap_mm=d))
    return dict(scope='inter-module nominal outer-envelope OBB screen; not moving finger/optical screen',
        tested_pairs=sum(a['group']!=b['group'] for a,b in itertools.combinations(parts,2)),
        required_projection_gap_mm=P['gap_screen_mm'],flagged_pairs=pairs,obb_passes=not pairs)

def radial_max(p):
    # Exact external radial envelope for z-parallel or tangent-axis cylinders and all box corners.
    if p['shape']=='box':return float(max(np.linalg.norm(corners(p)[:,:2],axis=1)))
    axis=p['axes'][:,0];c=p['center'];h,r=p['half'][0:2]
    if abs(axis[2])>.999:return float(np.linalg.norm(c[:2])+r)
    ax=axis[:2];perp=v([-ax[1],ax[0]])
    t=np.dot(c[:2],ax);rr=abs(np.dot(c[:2],perp))
    return math.hypot(rr+r,max(abs(t-h),abs(t+h)))

def envelope(parts):
    pts=np.concatenate([corners(p) for p in parts])
    return dict(nominal_outer_shape_coaxial_diameter_mm=2*max(radial_max(p) for p in parts),
        conservative_obb_diameter_mm=float(2*max(np.linalg.norm(pts[:,:2],axis=1))),
        z_min_mm=float(pts[:,2].min()),z_max_mm=float(pts[:,2].max()),depth_mm=float(np.ptp(pts[:,2])),
        motor_only_coaxial_diameter_mm=2*max(radial_max(p) for p in parts if p['kind']=='motor'),
        largest_radius_component=max(parts,key=radial_max)['name'],
        exclusions='gear enclosure, wiring, boltheads, complete moving fingers, full optical components')

def force(T,delta=45,b=7,d=30):
    a,be,de=map(math.radians,[20,35,delta]);dm=d-b*math.sin(de);Ft=2000*T/dm
    low=Ft/math.cos(be)*(math.tan(a)*math.sin(de)-math.sin(be)*math.cos(de))
    high=Ft/math.cos(be)*(math.tan(a)*math.cos(de)+math.sin(be)*math.sin(de))
    fa2=Ft/math.cos(be)*(math.tan(a)*math.sin(de)+math.sin(be)*math.cos(de))
    fr2=Ft/math.cos(be)*(math.tan(a)*math.cos(de)-math.sin(be)*math.sin(de))
    return dict(torque_Nm=T,mean_pitch_diameter_mm=dm,Ft_N=Ft,convex_Fa_N=low,convex_Fr_N=high,
        concave_Fa_N=fa2,concave_Fr_N=fr2,max_radial_resultant_N=max(math.hypot(Ft,high),math.hypot(Ft,fr2)),max_abs_axial_N=max(abs(low),abs(fa2)))

def bearing_beam(F,x,Fa,T,contact=0):
    # Geometrical center supports, not SKF pressure centers; conservative lever screen only.
    a,b=35.,45.;L=b-a;c=64.
    couple=abs(Fa)*x  # axial force at mean pitch radius adds an overturning couple
    RB=(F*(x-a)+contact*(c-a)-couple)/L;RA=F+contact-RB
    loads=[(x,-F),(a,RA),(b,RB),(c,-contact)]
    moment=lambda q:sum(f*(q-t) for t,f in loads if t<=q)-(couple if q>=x else 0)
    M=max(abs(moment(q)) for q,_ in loads);d=12;E=P['shaft_E_MPa_assumption'];I=math.pi*d**4/64
    # Overhung gear displacement with simple supports, no bearing/housing compliance.
    ell=a-x;deflection=F*ell**2*(ell+L)/(3*E*I)+couple*ell*(3*ell+2*L)/(6*E*I)
    sigma=32*M/(math.pi*d**3);tau=16*T*1000/(math.pi*d**3)
    return dict(gear_radial_N=F,external_axial_N=Fa,contact_N=contact,gear_load_coordinate_t_mm=x,
        axial_force_overturning_couple_Nmm=couple,reaction_A_N=RA,reaction_B_N=RB,max_bending_Nmm=M,gross_bending_MPa=sigma,gross_torsion_MPa=tau,
        gross_axial_MPa=Fa/(math.pi*d*d/4),gross_von_mises_MPa=math.sqrt((sigma+Fa/(math.pi*d*d/4))**2+3*tau**2),gear_deflection_mm_no_contact=deflection if contact==0 else None,
        single_C0_over_max_geometric_radial_reaction=3800/max(abs(RA),abs(RB)),
        limitation='conservative co-aligned radial/axial maxima including eccentric axial moment; not an equivalent bearing load or safety factor; induced thrust, clearance, minimum load, fits, notches, housing compliance and fatigue unresolved')

def mechanics():
    f=force(3.7);x=f['mean_pitch_diameter_mm']/2
    cases=[bearing_beam(f['max_radial_resultant_N']*k,x,f['max_abs_axial_N']*k,3.7*k) for k in [1,1.5,2]]
    contacts=[bearing_beam(f['max_radial_resultant_N'],x,f['max_abs_axial_N'],3.7,c) for c in [-50,50]]
    return dict(gear_force=f,reference_torque_ratio=min(7.74,7.34)/3.7,
        catalog_conditions=dict(rpm=100,cycles='>1e7',bending_bidirectional_stress_factor=2/3,lubricant_cSt_at_50C=100,uniform_motor_and_load=True,reference_only=True),
        proposed_90_deg_in_5s_mean_rpm=3,shaft_bearing_geometric_screen=cases,
        external_contact_50N_each_sign_cases=contacts,
        key_4x4x8_assumption=dict(shear_MPa=2*3700/(12*4*8),bearing_MPa=4*3700/(12*4*8)),
        transmission_sensitivity=[dict(assumed_efficiency=eta,output_Nm_at_3_7Nm_motor=3.7*eta,required_input_Nm_for_3_7Nm_output=3.7/eta) for eta in [.85,.9,.95,1]],
        NBK_twist_deg_at_3_7Nm=math.degrees(3.7/87),SKF_CB_axial_clearance_um=[15,23],
        catalog_parts_without_motors_subtotal_kg=8*.052+16*.036+4*.016+8*(.006+.002))

def mass_budget(parts):
    # Catalog masses override envelope volumes for bought parts. Custom parts are
    # nominal stock/envelope estimates, not weighed manufacturing parts.
    catalog=[dict(item='four motor-gearbox-encoder combinations',qty=4,each_g=151.4,basis='28.9 + 109 + 13.5 g; factory adapter/flange excluded'),
             dict(item='MMSB1.5-20 gears',qty=8,each_g=52,basis='KHK catalog'),
             dict(item='7201 BECBP bearings',qty=16,each_g=36,basis='SKF catalog rounded mass'),
             dict(item='MJC20 couplings',qty=4,each_g=16,basis='NBK largest-bore mass reference, exact 6/10 variant pending'),
             dict(item='KM1 nuts',qty=8,each_g=6,basis='SKF catalog'),
             dict(item='MB1 washers',qty=8,each_g=2,basis='SKF catalog')]
    for r in catalog:r['subtotal_g']=r['qty']*r['each_g']
    density={'shaft':.00785,'shaft_shoulder':.00785,'shaft_thread':.00785,'spacer':.00785,
             'gear_retention':.00785,'bolt_allowance':.00785,'housing':.00270,'housing_lip':.00270,
             'carrier_plate':.00270,'motor_mount':.00270,'finger_hub':.00270}
    categories={}
    for p in parts:
        if p['kind'] not in density:continue
        h=p['half'];vol=math.pi*(h[1]**2-(p.get('bore_mm',0)/2)**2)*2*h[0] if p['shape']=='cylinder' else float(np.prod(2*h))
        categories[p['kind']]=categories.get(p['kind'],0)+vol*density[p['kind']]
    known=sum(r['subtotal_g'] for r in catalog);custom=sum(categories.values())
    located=[]
    def record(label,mass,center,basis):located.append(dict(item=label,mass_g=mass,center_head_mm=v(center).tolist(),basis=basis))
    for p in parts:
        if p['kind'] in density:
            h=p['half'];vol=math.pi*(h[1]**2-(p.get('bore_mm',0)/2)**2)*2*h[0] if p['shape']=='cylinder' else float(np.prod(2*h))
            record(p['name'],vol*density[p['kind']],p['center'],'nominal native envelope volume x assumed density; pockets/keyways omitted')
    for group in range(4):
        group_parts=[p for p in parts if p['group']==group];by={p['name'].split('_',1)[1]:p for p in group_parts};prefix=group_parts[0]['name'].split('_',1)[0]
        front=by['motor']['center']+35.05*Z
        for label,m,c in [('gearhead',109,front-21.8*Z),('motor',28.9,front-51*Z),('encoder',13.5,front-64.25*Z)]:
            record(prefix+'_'+label,m,c,'catalog mass assigned to nominal axial sub-envelope centroid; not vendor measured CoM')
        for role in ['input','output']:
            pp=[by[role+'_gear_tooth_envelope'],by[role+'_gear_hub']]
            weights=[math.pi*(x['half'][1]**2-6**2)*2*x['half'][0] for x in pp]
            record(prefix+'_'+role+'_gear',52,sum(w*p['center'] for w,p in zip(weights,pp))/sum(weights),'catalog mass distributed over nominal gear envelope, not tooth-resolved CoM')
            for side in ['A','B']:record(prefix+'_'+role+'_bearing_'+side,36,by[role+'_bearing_'+side]['center'],'catalog mass at annular native envelope centroid')
            record(prefix+'_'+role+'_KM1',6,by[role+'_KM1']['center'],'catalog mass at nominal nut centroid')
            record(prefix+'_'+role+'_MB1',2,by[role+'_MB1_allowance']['center'],'catalog mass at simplified washer centroid; bent tabs omitted')
        record(prefix+'_coupling',16,by['coupling']['center'],'NBK reference mass at nominal coupling centroid')
    total=sum(x['mass_g'] for x in located);com=sum(x['mass_g']*v(x['center_head_mm']) for x in located)/total
    if not math.isclose(total,known+custom,rel_tol=1e-12):raise AssertionError('mass account mismatch')
    allowances=[('keys, screws, mounting bosses, shims and washers beyond modeled KM/MB and gear front bolt envelopes',40,90),
        ('factory motor adapter/flange and unmodeled connection hardware',20,50),
        ('four structural light fingers and contact pads',180,320),
        ('four LEDs/diffusers, center light/display and thermal spreaders',100,220),
        ('two ZED X One S cameras',72,72),
        ('camera mounts and on-head electrical boards',80,160),
        ('gear covers, lubrication, outer armor and seals',180,330),
        ('head rear carrier, detachable wrist interface and local cable restraint',150,300),
        ('on-head connectors and wiring, excluding long external bench cables',60,120)]
    rows=[dict(item=a,low_g=b,high_g=c,status='planning allowance, not a selected weighed part' if b!=c else 'manufacturer camera nominal 36 g each') for a,b,c in allowances]
    com_ranges=[([-15,-15,-90],[15,65,45]),([-25,-10,-135],[25,75,-65]),([-80,-80,0],[80,100,130]),([-80,-80,0],[80,100,130]),([-60,-60,-40],[60,60,0]),([-65,-65,-90],[65,65,10]),([-40,-40,-120],[40,60,40]),([-30,-30,-180],[30,30,-90]),([-60,-60,-165],[60,60,30])]
    for row,(lo,hi) in zip(rows,com_ranges):row['planning_CoM_head_mm_range']=[lo,hi]
    return dict(catalog_items=catalog,catalog_subtotal_g=known,custom_nominal_gross_by_kind_g=categories,
        custom_nominal_gross_subtotal_g=custom,drive_nominal_gross_estimate_g=known+custom,
        drive_CoM_head_mm_nominal_allocation=com.tolist(),mass_locations=located,
        CoM_limit='Nominal native geometry centroids with catalog masses; not measured/manufacturer CoM. Complete head and moving fingers are absent.',
        density_assumptions_g_per_mm3={'steel':.00785,'aluminum':.00270},
        allowances=rows,complete_head_planning_range_g=[known+custom+sum(r['low_g'] for r in rows),known+custom+sum(r['high_g'] for r in rows)],
        recommended_arm_sensitivity_head_masses_kg=[3.5,4.0,4.5],
        exclusions=['holding brake/positive latch not selected','full on-head four-axis drive boards if external routing changes','actual final CAD mass and measurements'],
        scope='catalog subtotal plus gross custom envelope estimates plus explicit planning allowances; not guaranteed lower/upper physical mass')

def self_checks(m,parts,rows):
    f=m['gear_force'];checks={}
    checks['torque_force_reverse']=math.isclose(f['Ft_N']*f['mean_pitch_diameter_mm']/2000,3.7,rel_tol=1e-12)
    checks['90deg_force_swap']=math.isclose(f['convex_Fa_N'],f['concave_Fr_N'],abs_tol=1e-10) and math.isclose(f['convex_Fr_N'],f['concave_Fa_N'],abs_tol=1e-10)
    # Reproduce KHK Table 12.6 example to its printed rounding.
    test=force(1.6646,math.degrees(math.atan(.5)),15,40)
    checks['KHK_published_example']=abs(test['Ft_N']-100)<.01 and abs(test['convex_Fa_N']+42.8)<.06 and abs(test['convex_Fr_N']-71.1)<.06
    checks['16_bearings']=sum(p['kind']=='bearing' for p in parts)==16
    checks['all_motor_axes_z']=all(np.allclose(r['input_axis'],[0,0,-1]) for r in rows)
    checks['gear_axes_90deg']=all(abs(np.dot(r['input_axis'],r['output_axis']))<1e-12 for r in rows)
    checks['hub_centers_preserve_roots']=all(np.allclose(r['root_anchor_mm'],r['finger_hub_center_mm'],atol=1e-10) for r in rows)
    checks['root_radius_70']=all(math.isclose(np.linalg.norm(r['root_anchor_mm'][:2]),70,abs_tol=1e-10) for r in rows)
    checks['gear_bore_length']=math.isclose(28-11.5,P['gear_I_mm'],abs_tol=1e-12)
    checks['coupler_two_insertions']=math.isclose(89-79,10) and math.isclose(69-59,10)
    checks['shaft_force_moment_balance']=all(abs(c['reaction_A_N']+c['reaction_B_N']-c['gear_radial_N']-c['contact_N'])<1e-8 and abs(c['reaction_B_N']*10-c['gear_radial_N']*(c['gear_load_coordinate_t_mm']-35)-c['contact_N']*29+c['axial_force_overturning_couple_Nmm'])<1e-7 for c in m['shaft_bearing_geometric_screen']+m['external_contact_50N_each_sign_cases'])
    c=m['shaft_bearing_geometric_screen'][0];ell=(35-c['gear_load_coordinate_t_mm'])/1000
    si=(c['gear_radial_N']*ell**2*(ell+.010)/(3*205e9*(math.pi*.012**4/64))+(c['axial_force_overturning_couple_Nmm']/1000)*ell*(3*ell+2*.010)/(6*205e9*(math.pi*.012**4/64)))*1000
    checks['SI_mm_deflection_match']=math.isclose(si,c['gear_deflection_mm_no_contact'],rel_tol=1e-12)
    checks['physical_cylinder_enclosed_by_obb']=all(radial_max(p)<=max(np.linalg.norm(corners(p)[:,:2],axis=1))+1e-8 for p in parts)
    if not all(checks.values()):raise AssertionError(checks)
    return checks

def solid(p,cq):
    c,u,er,h=p['center'],p['axes'][:,0],p['axes'][:,1],p['half']
    if p['shape']=='cylinder':
        sh=cq.Solid.makeCylinder(float(h[1]),float(2*h[0]),cq.Vector(*(c-h[0]*u)),cq.Vector(*u))
        if p.get('bore_mm',0):sh=sh.cut(cq.Solid.makeCylinder(p['bore_mm']/2,float(2*h[0]+.2),cq.Vector(*(c-(h[0]+.1)*u)),cq.Vector(*u)))
        return sh
    plane=cq.Plane(origin=cq.Vector(*c),xDir=cq.Vector(*u),normal=cq.Vector(*p['axes'][:,2]))
    return cq.Workplane(plane).box(*map(float,2*h)).val()
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

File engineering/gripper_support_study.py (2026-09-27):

#!/usr/bin/env python3
# SPDX-License-Identifier: CC-BY-NC-4.0
# Required Notice: Odradek — Auromix contributors (https://github.com/Auromix/odradek)
"""R4-support-01: independent shaft/load/envelope study, NOT manufacturing CAD.

Run with the repository engineering environment. numpy/matplotlib required;
--cad additionally requires cadquery. Never modifies shared layout parameters.
All geometry is nominal mm. SI calculations are explicitly cross-checked.
"""
from pathlib import Path
import argparse, hashlib, itertools, json, math
import numpy as np

ROOT = Path(__file__).resolve().parents[1]
EXPECTED = '4349d1797b906b67a7bc396fcb84bc439c2d70dd0b337659e552cee293d2dd81'
OUT = ROOT / 'engineering/generated/gripper-support'
P = dict(revision='R4-support-01', motor_body_length_mm=70.1, motor_body_diameter_mm=22.,
         motor_shaft_length_mm=16.3, motor_shaft_diameter_mm=6.,
         coupling_diameter_mm=20., coupling_length_mm=30., coupling_insertion_mm=10.,
         bearing_d_mm=10., bearing_D_mm=26., bearing_B_mm=8.,
         pulley_L_mm=.812*25.4, pulley_W_mm=.400*25.4, pulley_E_mm=.306*25.4,
         pulley_flange_D_mm=1.250*25.4, pulley_hub_D_mm=.776*25.4,
         pulley_tooth_OD_mm=1.098*25.4, belt_width_mm=9., belt_thickness_allowance_mm=3.,
         pulley_teeth=30, pitch_mm=3., center_distance_mm=45., axis_z_difference_mm=25.,
         belt_plane_u_mm=2.5, bearing_to_pulley_gap_mm=2., plate_thickness_mm=10.,
         retention_bay_mm=4., coupling_to_retention_gap_mm=1., shaft_diameter_mm=10.,
         input_shaft_length_mm=65., output_shaft_length_mm=67.,
         head_diameter_reference_mm=210., required_projection_gap_mm=1.)

def v(x): return np.array(x, dtype=float)
Z=v([0,0,1])

def stack():
    # Drawing Type 6F: E is the projecting hub; L includes flange stack.
    # Hub faces -u. The centered flange allocation is a nominal drawing reading.
    half=(P['pulley_L_mm']-P['pulley_E_mm'])/2
    a=-half-P['pulley_E_mm']; b=half; gap=P['bearing_to_pulley_gap_mm']
    ba=[a-gap-P['bearing_B_mm'],a-gap]; bb=[b+gap,b+gap+P['bearing_B_mm']]
    pa=[a-gap-P['plate_thickness_mm'],a-gap]
    pb=[b+gap,b+gap+P['plate_thickness_mm']]
    ra=[pa[0]-P['retention_bay_mm'],pa[0]]
    rb=[pb[1],pb[1]+P['retention_bay_mm']]
    cr=ra[0]-P['coupling_to_retention_gap_mm']; cl=cr-P['coupling_length_mm']
    front=cl-(P['motor_shaft_length_mm']-P['coupling_insertion_mm'])
    inp=[cr-P['coupling_insertion_mm'],cr-P['coupling_insertion_mm']+P['input_shaft_length_mm']]
    hub=[rb[1]+1,rb[1]+11]
    op=[ra[0]-2,ra[0]-2+P['output_shaft_length_mm']]
    return dict(pulley_limits=[a,b],flange_limits=[-half,half],hub_limits=[a,-half],
                bearing_A=ba,bearing_B=bb,plate_A=pa,plate_B=pb,retention_A=ra,retention_B=rb,
                coupling=[cl,cr],motor_body=[front-P['motor_body_length_mm'],front],
                motor_shaft=[front,front+P['motor_shaft_length_mm']],input_shaft=inp,output_shaft=op,
                finger_hub=hub,bearing_centers=[sum(ba)/2,sum(bb)/2])

def box(name, group, c, axes, half, kind, **extra):
    return dict(name=name,group=group,center=v(c),axes=np.column_stack(axes),half=v(half),kind=kind,**extra)

def sat(a,b):
    A=a['axes']; B=b['axes']; delta=b['center']-a['center']
    axes=np.concatenate([A.T,B.T,np.cross(A.T[:,None,:],B.T[None,:,:]).reshape(-1,3)])
    axes=axes[np.linalg.norm(axes,axis=1)>1e-9]; axes/=np.linalg.norm(axes,axis=1)[:,None]
    gaps=np.abs(axes@delta)-np.abs(axes@A)@a['half']-np.abs(axes@B)@b['half']
    return float(max(gaps))

def corners(a):
    return a['center']+np.array(list(itertools.product([-1.,1.],repeat=3)))*a['half']@a['axes'].T

def envelope(parts):
    pts=np.concatenate([corners(x) for x in parts]); r=np.linalg.norm(pts[:,:2],axis=1)
    return dict(coaxial_obb_enclosing_diameter_mm=float(2*max(r)),z_min_mm=float(pts[:,2].min()),
                z_max_mm=float(pts[:,2].max()),depth_mm=float(np.ptp(pts[:,2])),
                aabb_min_mm=pts.min(axis=0).tolist(),aabb_max_mm=pts.max(axis=0).tolist())
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

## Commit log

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2026-09-27 Extract true joint interfaces and generate printable fit coupons
    [ODR-CPN-RH14-N-R4.csv, ODR-CPN-RH14-N-R4.dxf, ODR-CPN-RH14-N-R4.step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]
2026-09-27 Build sourced hardware BOM and internal harness architecture
    [bom.csv]
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2026-09-27 Build printable manual finger fixture with dimensions and geometry checks
    [BOM.csv, assembly-lower-q107p127.step, assembly-lower-q126p000.step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]
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2026-09-27 Generate 7 plus 4 axis CAD Blender and analytic petal closure evidence
    [BASE_layout.step, BASE_layout.stl, CAM_-1_lens.step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]
2026-09-27 Develop actual J1 and J7 mount candidates against vendor solids
    [J1-fixed-hole-coordinates.csv, J1-oem-head-reliefs.csv, J7-output-hole-coordinates.csv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]
2026-09-27 Resolve four finger EtherCAT topology and separated head power branches
    [bom.csv]
2026-09-27 Select complete dual fisheye GMSL optical bench and fixed software versions
    [optical-bench-bom.csv]
2026-09-27 Specify a sourced single-axis EtherCAT bench and unresolved enable gates
    [single-axis-bench-bom.csv]
2026-09-27 Design open J1 base with verified vendor clearances and overturning screen
    [ODR-BASE-BACK-R4.dxf, ODR-BASE-BACK-R4.step, ODR-BASE-BACK-R4.stl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]
2026-09-27 Select LED matrices head IO and quantified power branches
    [head-lighting-io-bom.csv]
2026-09-27 Reject compact belt layout after adding real pulley widths and shaft supports
    [R4-support-01-envelope.step, gripper-support-bom.csv, single-finger-envelope.step]
2026-09-27 Draw traceable 609 pixel lighting projection and electrical coordinate reference
    [led-coordinate-reference.csv, led-front-projection.dxf]
2026-09-27 Sync head lighting selections into scoped system BOM
    [bom.csv]
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2026-09-27 Evaluate axial miter drives with shaft support loads and mass rollup
    [R4-support-02-envelope.step, gripper-miter-support-bom.csv, single-miter-module.step]
2026-09-27 feat: capture upper-petal electronics and replace NRND thermistor
    [bom.csv, external-interface-bom.csv, head-lighting-io-bom.csv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]
2026-09-27 feat: validate distal contact shoes against finite cylinders
    [LL_light.step, LL_pad_minus.step, LL_pad_plus.step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]
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2026-09-27 feat: model removable narrow-root forks and certify nominal motion gaps
    [R4-support-03-closed.step, R4-support-03-open.step, gripper-root-support-bom.csv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]
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2026-09-27 feat: close the J5 to J6 structural connection in nominal CAD
    [ODR-L56-CARRIER-R4.dxf, ODR-L56-CARRIER-R4.step, ODR-L56-CARRIER-R4.stl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]
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2026-09-27 fix: distinguish grasp-force witnesses from minimum actuator capacity
2026-09-27 Add native Blender reviews for connection base and contact fingers
    [odradek-r4-subassemblies.blend]
2026-09-27 Model recessed molded keys for distal contact pad retention
    [ODR-RET-LOWER-BLADE.step, ODR-RET-LOWER-BLADE.stl, ODR-RET-LOWER-COUPON.step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]
2026-09-27 Package four P16 drives with verified shoulder pins and motion bounds
    [P16-PACK-01-closed.step, P16-PACK-01-open.step, base_bracket.step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]
2026-09-27 Build shoulder support with ribbed output plate and verified assembly path
    [ODR-L12-FORK-R4.dxf, ODR-L12-FORK-R4.step, ODR-L12-FORK-R4.stl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]
2026-09-27 Fit recessed LED layers and PCB mounts with blade compliance screening
    [LOWER-PCB_outline.step, LOWER-SSH_M2_4_1.step, LOWER-SSH_M2_4_2.step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]
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2026-09-27 Add routed ULP02 four-layer LED prototype with native KiCad checks
    [bom.csv, external-interface-bom.csv, led-placement-reference.csv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]
2026-09-27 Keep regenerated router intermediate out of ULP02 deliverables
    [upper-petal.dsn]
2026-09-27 Add J6 J7 wrist load path CAD and checked assembly drawings
    [ODR-L67-CARRIER-R4.dxf, ODR-L67-CARRIER-R4.step, ODR-L67-CARRIER-R4.stl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]
2026-09-27 Add J2 J3 load path with continuous insertion and CAD inertia checks
    [ODR-L23-CARRIER-R4.dxf, ODR-L23-CARRIER-R4.step, ODR-L23-CARRIER-R4.stl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]
2026-09-27 Integrate four finger carrier and real camera packaging with wrist collision evidence
    [P16-CARRIER-01-closed.step, P16-CARRIER-01-open.step, base-bracket.step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]
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2026-09-27 Add 24mm J7 extension and continuous head wrist clearance proof
    [ODR-J7-EXT24.dxf, ODR-J7-EXT24.step, ODR-J7-EXT24.stl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]
2026-09-27 Refine P16 finger roots with continuous clearance and net-section evidence
    [LL_integral_steel_crank_spindle.step, LL_metal_blade_with_narrow_tongue.step, P16-CARRIER-02-closed.step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]
2026-09-27 Calculate conditional four-channel P16 drive and feedback interface
    [actuator-interface.csv, feedback-angle-table.csv]
2026-09-27 Model J3-J4 structural bridge with full-turn interface and assembly checks
    [ODR-L34-CARRIER-R4.dxf, ODR-L34-CARRIER-R4.step, ODR-L34-CARRIER-R4.stl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]
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2026-09-27 Add raised shoulder candidate with continuous local clearance proof
    [RAISE01-L12-front_ring.step, RAISE01-L12-output_adapter.step, RAISE01-L12-rear_fork.step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]
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2026-09-27 Integrate raised shoulder through full arm math collision and native Blender
    [odradek-integrated-7-plus-4.blend]
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2026-09-27 Model removable 285-pixel display with continuous clearance and assembly checks
    [CD01-GH12-mated-reference.step, CD01-L-M2-nut-envelope.step, CD01-L-M2x20-envelope.step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]
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2026-09-27 Evaluate reinforced raised shoulder with remote steel thread blocks
    [L12_front_ring.step, L12_output_adapter.step, L12_rear_fork.step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]
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2026-09-28 Compare shoulder fork stiffness with converged quadratic tetrahedral studies
    [RAISE01-rear-fork-world.step, RAISE02-rear-fork-world.step]
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2026-09-28 Audit 50 to 120 mm box and can contact range and expose rigid coupling failures
    [summary.csv]
2026-09-28 Select single head servo candidates with verified pin mapping and thermal limits
    [candidate-bom.csv, connection-map.csv, cycle-demand.csv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]
2026-09-28 Track finite workpiece contact failures in the active engineering baseline
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2026-09-28 Rebuild shaped petal layers for orthogonal radial gripping with verified clearances
    [LED_front_reservation.step, PCB_blank_reservation.step, R5-PETAL-FORM02-four-petal-form.step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]
2026-09-28 Design detachable eRob wrist adapter with real output interface and assembly gauges
    [adapter-gauge-print-oriented.stl, adapter-gauge.step, adapter-gauge.stl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]
2026-09-28 Verify folded belt transmission packaging and added inertia for legacy slider candidate
    [added-inertia-sensitivity.csv, bom.csv, tension-and-bearing-loads.csv]
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2026-09-28 Build two-axis eRob wrist connector and clear fixed bolts without axial extension
    [A01-P-G-print-oriented.stl, A01-P-G.step, A01-P-G.stl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]
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2026-09-28 Model passive petal opening and stop at the first rope-incompatible event
    [opening-until-first-event.csv]
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2026-09-28 Fix shared-endpoint reflection in wrist section drawings and add translated regression
    [A01-P.dxf, H01-reuse.dxf, W01.dxf]
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2026-09-28 Build lightweight eRob J5 to J6 closed-tube link with sourced interfaces and cable counterexample
    [L56-E01.step, L56-E01.stl, L56-G-print-oriented.stl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]
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2026-10-09 Fix native base IO BOM and verify reopened schematic synchronization
    [B06-IO-Native-BOM.csv]
2026-10-09 Make B06 base independently buildable with standalone test rig and qualification gates
    [B06-101-LOAD-DECK.step, B06-102-REAR-WEB.step, B06-103-LOWER-JAW.step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]
2026-10-09 Refine B06 weld geometry and manufacturing definition with local lamp supply target
    [B06-101-LOAD-DECK.step, B06-102-REAR-WEB.step, B06-103-LOWER-JAW.step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]
2026-10-09 Implement local 5V lamp supply in B06 native IO board
    Add a protected 48V branch and seven parts in the editable JLCEDA project. Reposition packages around coax bracket and driver paths, preserve existing copper, and bind reopened DRC and manufacturing 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
    Refresh standalone Blender assembly, five-part print package, 74-line manufacturing BOM and review archive. Add base-only rail qualification case; all 21 physical tests remain unmeasured and PWM cont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
    [B06-101-LOAD-DECK.step, B06-102-REAR-WEB.step, B06-103-LOWER-JAW.step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]
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

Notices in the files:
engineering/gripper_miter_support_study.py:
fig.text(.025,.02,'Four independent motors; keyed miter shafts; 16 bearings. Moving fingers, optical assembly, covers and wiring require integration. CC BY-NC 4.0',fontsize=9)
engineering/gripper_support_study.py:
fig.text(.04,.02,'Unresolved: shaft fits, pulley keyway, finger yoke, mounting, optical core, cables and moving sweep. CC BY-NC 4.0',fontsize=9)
